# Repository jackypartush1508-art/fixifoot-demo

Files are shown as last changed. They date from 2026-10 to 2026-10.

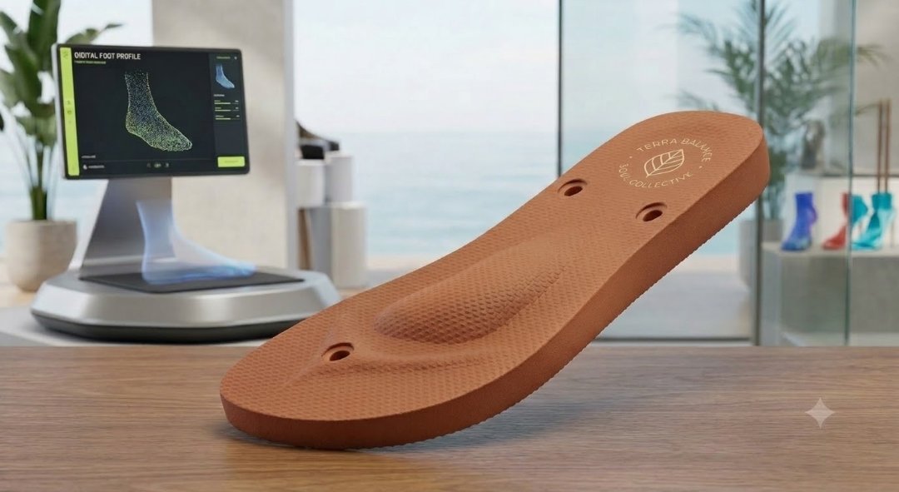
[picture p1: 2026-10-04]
assets/insole-fullcontact.jpg

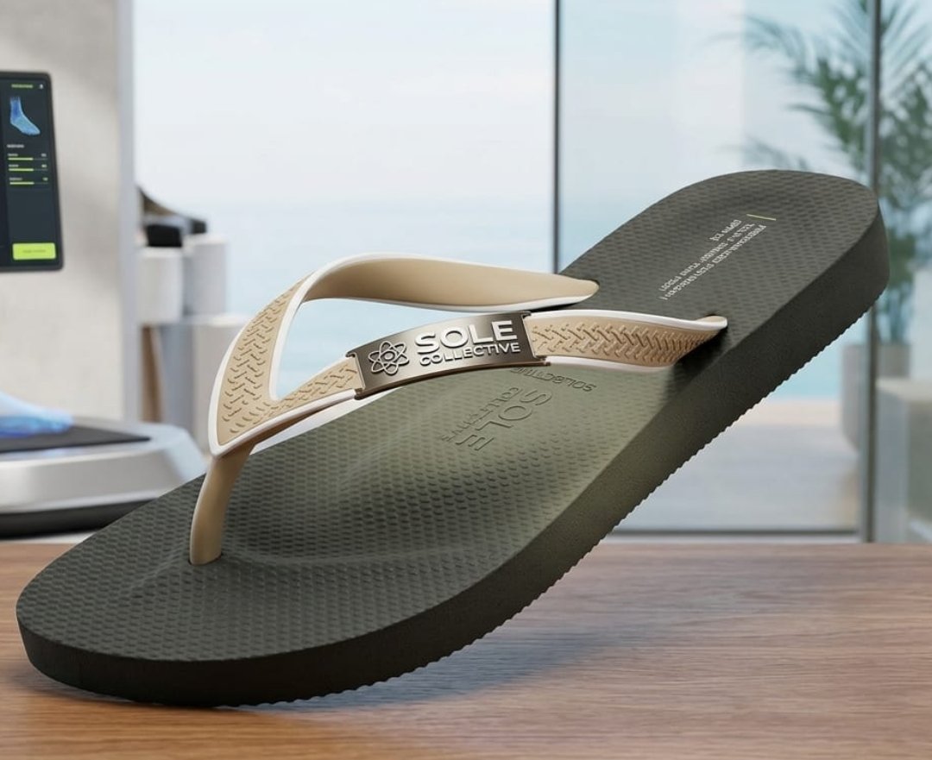
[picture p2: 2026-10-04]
assets/flipflop-classic.jpg

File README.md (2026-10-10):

# Fixifoot Philippines – custom insole & flip-flop DEMO

Static web app (no build step). Serve the folder and open on a phone:

    python3 -m http.server 8000      # then open http://<your-computer-ip>:8000
    # Camera needs HTTPS or localhost. For phones on Wi-Fi use e.g. `npx localtunnel` / ngrok, or upload a scan file.

## Files
- index.html, styles.css – UI (mobile-first)
- app.js       – flow, customer/staff mode, viewers, export
- rules.js     – EDIT ME: arch types, 21 foot problems -> insole changes, questionnaire, friendly wording, products, example prices
- geometry.js  – procedural foot, insole/sole/flip-flop/slide geometry, printable STL builder, template adaptation
- receipt.js   – v10 PDF receipt (jsPDF, vendored in vendor/jspdf.umd.min.js; DejaVu Sans subset in vendor/fonts/receipt-fonts.js)
- footwear.js  – v13 sandal straps, clog upper + heel strap, bed fit / print-time estimate
- engrave.js   – v9 initials engraving as real geometry (manifold-3d booleans, lazy-loaded)
- vendor/      – three.js r160 (vendored, works offline); manifold/ (manifold-3d 3.5.4, Apache-2.0); fonts/fx-font.js (Helvetiker Bold subset)
- assets/      – product photos, templates/ (Jacky's L90 + S90 insoles, repaired watertight STL)

## Modes
- Customer mode (default): simple words, one question per screen, "Your feet -> We'll add" summary.
- Staff mode: tap "🔒 Staff", PIN 1234 (change STAFF_PIN in app.js). Shows checklist, overrides, support settings, conflicts, template choice and "Send to production" (JSON spec + STL per foot).

## Shortcuts for demos
    ?demo=flat&cond=plantar_fasciitis,metatarsalgia&product=fullcontact&screen=s-result&staff=1

## What is simulated
Camera capture is a demo animation; measurements for a demo scan are generated. Real 3D phone scanning needs a native app
(iPhone TrueDepth/LiDAR via ARKit, or an Android photogrammetry SDK). Uploading a real STL/OBJ scan works.
Not a medical device – comfort product; refer diabetes/pain to a podiatrist.

## v3 (Oct 2026)

### Realistic 3D foot, full 360°
- Foot mesh: **"Blender Foot realistic" by Dan Ulrich / Blender Studio** (Human Base Meshes bundle v1.2.0), **CC0 1.0 public domain** –
  https://commons.wikimedia.org/wiki/File:Blender_Foot_realistic_by_Dan_Ulrich_(CC0).stl .
  Decimated 3.0M → 34k triangles, cut at 118 mm (ankle) and capped, mirrored for the right foot, stored in `assets/foot-scan.js` (int16).
  At runtime it is scaled to the scanned length/width, mirrored for L, and the medial arch is deformed per arch type (high +7 mm, low −3.5, flat −6.5 at ~41 % of length).
- Viewer: TrackballControls (no polar limits – rotate over the top and under the sole), pinch/scroll zoom, auto-spin on load,
  preset views Top / Bottom / Inside / Outside / Back / Front, Right / Left / Both, toggles: 🔥 plantar pressure, 🕸 mesh wireframe, ✨ scan look (point cloud shimmer).

### Branding
- Logo: official Fixifoot logo from https://fixifoot.ph/wp-content/uploads/2023/10/fxf_horizontal_logo-21_2.webp → `assets/logo.png` (swap this one file to change it).
- Palette (Elementor global colours on fixifoot.ph): primary `#0099FF`, deep blue `#015AD8`, dark `#162327`, accent yellow `#FFD22E`, light grey `#ECECEC`, black text `#000000` (+ secondary blues `#0A6EBD`, `#5A96E3`, `#A1C2F1`).

### On-device CRM (staff → 📇 Customers)
localStorage key `fxCRM_v1`: name, phone, L/R scan data (incl. 48×24 plantar height grid for uploaded scans), detected problems, settings, order history.
Search by name/phone/order no. **New order from saved scan** regenerates spec + both STLs without rescanning. Two demo customers are seeded on first run.

### Clinical review (staff → 🩺 Clinical rationale)
Arch apex ~41 % of foot length (navicular); arch by type high 20 / normal 15 / low 12 (cap 16) / flat 10 (cap 14) mm;
heel cup 12 standard – 14/16 control – 18-20 deep (KevinRoot, Pacific Orthotic Rx); medial post 4° std, max 6°; lateral wedge ≤5°;
met pad apex 6–11 mm proximal to met heads 2-4 (~66 % length; Hastings 2007); heel lift ≤6 mm in-shoe, >10 mm external (Cochrane 2021, OHI);
zone thickness heel ~3 mm → forefoot ~1.8 mm (sulcus); diabetic: total contact, ≥6.4 mm (1/4") cushioning, no posting, rounded edges (IWGDF 2023, CMS LCD L33369).
**Total contact**: when a real scan (STL/OBJ) is uploaded the insole top follows the scanned plantar surface (rearfoot + midfoot, 85 % of height); toggle in the dashboard.

## v4 (Oct 2026) – scan-accurate fitting (`fit.js`)

### 1. Auto-alignment of uploaded STL/OBJ (staff → 🧭 Scan alignment)
- Units: the scale (m / cm / mm) that makes the scan 150–1000 mm long. Staff can override.
- Clean-up: vertices welded, only the largest connected piece kept (floating debris removed).
- Up direction: sphere search (500 directions + hill-climb) for the direction whose lowest slab has the biggest touching area (the sole).
- Floor (plantar plane): RANSAC + refinement for a supporting plane under the lowest points (≤1 % of points may be below it), then tilt-corrected so the floor is at y = 0.
- Long axis: PCA of the footprint (<25 mm). Heel vs toe: the ankle/leg mass sits over the heel; without an ankle, the forefoot is the wider end.
- Left / right: the medial arch side is higher. If the arch is flat, the longest toe marks the inside.
- Ankle/leg above 40 mm is ignored for the plantar map, and the 3D view clips it.
- Staff view: aligned scan on the floor grid, trim plane, heel→toe arrow, auto-detected values, 2 mm plantar height map.
  Nudges: swap heel/toe, upside down, mirror L↔R, turn 90°, pitch/roll ±1°, yaw ±2°, units, reset.
  The scan is assigned to the detected foot, then the other foot is scanned or uploaded.

### 2. Full-length total contact
- The plantar surface is rasterised as a lower envelope on a **2 mm grid**. It uses only sole triangles flatter than ~65°, so side walls do not lift the rim. One light smoothing pass, and the surface is extended past the outline.
- Insole top = plantar surface × arch fill + one constant. Then:
  - heel cup walls rise from the **scanned heel contour**;
  - clinical modifications are added on top (met pad 6–11 mm behind the measured ball line, posts, wedge, heel lift, toe crest at the measured sulcus, Morton's extension, offload pockets).
- Thickness changes only linearly from heel to toe, so the foot can follow it as a rigid pitch. Bottom is flat on Z = 0.
- Arch fill by condition: default 100 %, arthritis 90 %, plantar fasciitis + high arch 95 %, diabetic always 100 %. Staff slider 70–100 %.
- The plantar height is capped 2 mm above the measured arch apex, so the rim never climbs the side of the foot.
- Outline = scanned footprint silhouette (<20 mm) + product allowance:
  - insole: side 1.5 / heel 1 / toe 6 mm, or trimmed to the shoe last length when an EU size is chosen;
  - flip-flop / slide: side 6 / heel 5 / toe 8 mm.

### 3. Template morphing (L90 / S90)
- XY warp, non-uniform and piecewise-linear along the length: knots at heel / template arch apex → scanned arch apex / template ball → scanned ball line / toe (S90 = 72 % coverage). Width maps onto the scanned outline row by row.
- Z: the top surface follows the plantar map + cup + mods. A single constant keeps ≥ the minimum thickness over the template's own curved bottom (98 % of the bed). The template rim shape is kept.

### 4. Flip-flop / slide
- Contoured footbed from the plantar map, flat outsole on Z = 0, 5 mm heel-to-toe drop (linear).
- Toe-post position = detected 1st/2nd toe gap (4 mm proximal). Strap ends = ball-line landmarks (ballU − 10 %).
- The coordinates are written to the spec (`strapHolesMm`, in the STL frame). Holes are **not** cut into the STL.

### 5. Fit check (staff → 📊 Fit check, badge on the dashboard)
- The product's top surface is rasterised on the same 2 mm grid.
- Foot placement = robust least-squares offset + tilt (the foot standing on the insole).
- gap = scanned sole − insole top. Positive = air gap, negative = pressure.
- Stats over the contact area (plantar height ≤25 mm, edge eroded 4 mm): mean |gap|, signed mean, max gap / pressure, p95, % within ±1 / ±2 mm.
- Intentional modifications are hatched and reported separately.
- **PASS** = mean |gap| < 1 mm and ≥ 80 % within ±1 mm. WARN < 1.6 mm. Otherwise FAIL.
- Views: 3D heat map with ghost foot, plus a 2D deviation map with ball line and toe-gap markers.

### 6. Test scans (`samples/v4-test-scans/`, generator `generate_test_scans.py`)
All test scans are deformations of the CC0 Blender foot (no real customer scan was available).
- flat 255 mm rotated
- high arch 275 mm in cm, rotated
- left foot in metres, Z-up, rotated
- original with leg (left, m, Z-up)
- noise 0.35 mm + debris
- 8° tilt
- low arch OBJ in cm

Results: `fit-results.json` / `fit-results-summary.txt`. All 8 got side, units, heel/toe and length right (±2 mm).
Plantar-map error vs ground truth: 0.02–0.34 mm mean (0.62 mm with noise).
Fit mean |gap|:
- 0.09–0.14 mm (noise scan 0.30–0.41 mm) for contact insole, L90, S90, flip-flop and slide;
- 98–100 % within ±1 mm (noise 93–96 %); p95 ≤ 0.6 mm (noise ≤ 1.5 mm).
All 32 exported STLs are watertight, winding-consistent and have Z = 0 at the bottom.
Limits: see the v4 report (the fit check measures against the same scan the product was built from; real feet deform under load).

## v5 (Oct 2026) – cloud CRM on Supabase (`cloud.js`, `config.js`, `supabase/`)

The CRM can live in Supabase (Postgres + Auth + Storage) instead of the browser. **The cloud switch is `config.js`:**

```js
window.FIXI_CLOUD = { url: 'https://<project-ref>.supabase.co', anonKey: '<anon / publishable key>' };
```

* Empty `config.js` (as published right now): fully offline demo, so the on-device CRM and staff PIN 1234 work exactly like v4.
* Filled `config.js`: the staff button opens **email + password sign in / create staff account / forgot password**. In cloud mode there is no PIN. If the network or the cloud is down, the app falls back to the PIN and the on-device CRM.
* Only the public anon key goes in the frontend; never put the service_role key in it. All access is enforced by row-level security (RLS).

**Database** (`supabase/migrations/20261004120000_fixifoot_crm.sql`)

| Object | What it holds and who can access it |
|---|---|
| `staff_profiles` | user_id, email, name, role pending / staff / admin. Created automatically on sign-up as **pending**. |
| `customers` | id, name, phone, email, notes, profile jsonb (questionnaire, overrides, settings), created_at/updated_at, created_by. |
| `scans` | customer_id, side L/R, source, `mesh_path` (raw scan STL in the `scans` bucket), `plantar_map` jsonb (2 mm height map), `metrics` jsonb, created_at/by. |
| `orders` | order_no, customer_id, product, color, size, problems/settings/spec jsonb, `stl_paths` (in the `stl` bucket), status, created_at/by. |
| Storage buckets `scans` and `stl` | Private, 50 MB per file. |

**Access rules (RLS)**

* anon has no grants at all.
* Pending users see nothing.
* staff can read, insert and update.
* Only admins can delete or change roles.
* Nobody can promote themselves.

**What the app does in cloud mode**

* 💾 Save customer upserts the customer and adds a scan row per changed foot, uploading the raw STL/OBJ scan as STL.
* Send to production and Re-order upload the generated STLs and spec and create an order.
* 📇 Customers loads from the cloud: search, detail, order history and re-order from the saved scan.
* **Customer-facing flow needs no login.** Orders placed without a staff session stay on the device. After signing in, staff see a **⬆️ Upload on-device customers** button.
* Admins get **👥 Staff accounts** to approve sign-ups (pending → staff / admin).

**Setting it up**

1. Apply the migration to the Supabase project.
2. Fill in `config.js`.
3. Add the site URL to Auth → URL configuration, so confirmation and reset emails come back to the app.
4. Jacky signs up in the app (Staff view → Create staff account) and confirms his email.
5. Run `supabase/promote_admin.sql` with his email.
6. Once all staff accounts exist, switch off **Auth → Sign In / Providers → Allow new users to sign up**. New staff are then invited from the dashboard (Auth → Users → Invite), or sign-ups are switched on briefly. Pending accounts have no data access in any case.

### v5 live status (4 Oct 2026)

**Project and keys**

* Supabase project **fixifoot**: ref `kbeplmkinzynpelatzqs`, region ap-southeast-1, free plan, URL https://kbeplmkinzynpelatzqs.supabase.co.
* `config.js` holds the **publishable** key only.

**Migrations applied**

* `fixifoot_crm`
* `private_role_helpers`: moves the SECURITY DEFINER role checks to a non-exposed `private` schema.

**Advisors and tests**

* Security and performance advisors: 0 findings.
* End-to-end test on the live site passed and its data was removed: pending / staff / admin permissions, save, upload, order, search, re-order, delete and sign-out.

**Email**

* With Supabase's built-in email sender, only email addresses of **members of the Supabase organization** are accepted. Others are rejected with `Email address "…" is invalid`.
* For other staff, either set up custom SMTP (Auth → Emails → SMTP settings) or create their user in Auth → Users → Add user, ticking "Auto confirm user".

## v6 (Oct 2026) – real holes and lattice in the STL (`openings.js`)

Ventilation holes (perforated insole) and lattice openings (lattice slide) used to be visual only (alpha textures). They are now **real geometry**: the 3D preview and the exported STL are the **same mesh**.

* **How it works (2D profile, no CSG):**
  * The sole is re-meshed on a tile grid in its own (length × across) parameter space.
  * Each tile that gets an opening is re-triangulated: a zipper between the tile border and the opening polygon, plus a vertical wall from top to bottom.
  * Every edge is shared by exactly two faces, so the mesh stays watertight and manifold.
  * It works on both the scan-based total-contact sole and the parametric sole.
* **Perforated insole:**
  * Through-holes of Ø 3 / 3.5 / 4 mm (12-sided).
  * Spacing Low 9 / Medium 7.5 / High 6.2 mm, staggered rows.
  * Kept solid: heel cup (first 25 % of length), medial arch support (25–62 %), toe end, a 5 mm edge margin and the metatarsal-pad dome when prescribed.
* **Lattice slide:**
  * Through hexagon cells: Low 12 mm / 2.4 mm walls, Medium 9.5 / 2.0, High 7.5 / 1.6.
  * Kept solid: a 7 mm perimeter rim and both strap-anchor bands.
* **Wall thickness:** at least 1.2 mm guaranteed (3 perimeters with a 0.4 mm nozzle). The target is 1.6 mm for holes and the preset wall for lattice. Each opening is checked against its tile border (≥ wall/2) and the outline (≥ rim), and is shrunk or skipped if it doesn't fit.
* **Staff controls:** Product & model → *Real ventilation holes / Real lattice openings* on/off, density/spacing, hole diameter. Live stats show the count, open area, min wall, rim and triangles. The setting is saved with the customer and written to the spec JSON (`product.openings`, `stlFiles[].openings`).
* **Template base (L90 / S90):** holes are **not** cut into template models. Use the parametric or scan sole for real openings.
* **Samples:** `samples/v6-perforated-insole-holes-{right,left}.stl`, `samples/v6-lattice-slide-sole-{right,left}.stl`.
* **Screenshots:** `screenshots/v6-*.png`
  * `v6-stl-*`: the exported STL rendered directly.
  * `v6-staff-*` and `v6-preview-*`: the in-app viewer.

## v6.1 (Oct 2026) – smooth forefoot, no ridges between the toes (`fit.js`)
- Scan-based surface (`deriveModel` → `md.sampleF`): from ~14 mm behind the metatarsal-head line forward the scanned relief is replaced by a
  robust, lower-envelope-weighted **quadratic surface** (1, t, t², s, s², s·t in a fixed ball-row frame) – a template-like forefoot with gentle toe
  spring. It is blended into the scanned arch/heel with a smoothstep over ~18 mm (ballU − 14 mm → ballU + 4 mm): no step, no kink.
- Used by every scan-based model (full-contact, perforated, slide, flip-flop, morphed templates). Prescribed modifications (met pad, toe crest,
  Morton's extension, reliefs) are still added on top. The parametric path was already analytic/smooth in the forefoot (verified).
- The fit check ignores the intentionally smoothed forefoot zone ("Smooth forefoot (no toe ridges)").
- Validation (trimesh, 1 mm ray grid, toe zone 4 mm → 24% of length from the tip, ≥ 6 mm inside the outline, residual to a cubic polynomial):
  before v6.1 max 6.9–8.8 mm (toe ridges), after **0.10–0.14 mm** (p99 0.07–0.08 mm); parametric 0.11–0.19 mm. All 20 STLs watertight, 1 body,
  min wall ≥ 1.68 mm. Curvature across the blend zone: max |d²z| 0.05 mm/mm² (was 1.16).
- Screenshots: `screenshots/v6.1-before-toes-*.png`, `v6.1-after-toes-*.png`, `v6.1-*-iso-*.png`, `v6.1-staff-*.png`. Samples: `samples/v6.1-*-{right,left}.stl`.

## v7 (Oct 2026) – Fixifoot insole line: 6 new models (`rules.js` PRODUCTS, `fit.js`, `geometry.js`, `app.js`)
Every model is built on the v6.1 smooth-toe surface (scan path) or the analytic parametric surface. Each product has `model` (real geometry),
`params` (forced clinical settings) and `print` (TPU print settings) – stored in the spec JSON (`print`, `model`, `recommended`) and shown in
staff mode (Product & model card → model geometry + TPU print settings table).

| Model | Geometry (STL) | Print |
|---|---|---|
| **Fixifoot Sport** | 8 → 6 mm (heel → forefoot), 18 mm heel cup, arch +1.5 mm | TPU 95A gyroid 20%, heel shock zone gyroid 35%, 85A soft top 1.2 mm |
| **Fixifoot Everyday** | 4 → 3 mm, 10 mm gentle heel cup, full-contact arch, real ventilation holes | TPU 90A gyroid 25%, 0.16 mm layers |
| **Fixifoot Diabetic Care** | 7 → 6.2 mm (min 6), total contact, 1.4 mm rounded rim, 1.5 mm smooth soft-insert pockets under met heads + hallux | varioShore / TPU 80–85A gyroid 15%, pockets 8% or PORON, 3 mm soft top cover |
| **Fixifoot Work & Stand** | 5.5 → 5 mm, strong arch +3 mm, 16 mm heel cup | TPU 92A, heel + ball cushion zones gyroid 12%, arch 35% |
| **Fixifoot Dress Slim** | 3/4 length (ends 6 mm past met-head line), 3 → 2.2 mm with skived front, met pad, 10 mm cup | TPU 95A solid, 0.12 mm layers |
| **Fixifoot Kids** | 3.2 → 2.2 mm flexible forefoot, arch fill 75%, 14 mm cup; thickness + cup scale with foot length (ref 240 mm) | TPU 85A gyroid 15%, forefoot 10% |

- Rule engine `recommendProduct()`: diabetes → Diabetic Care; foot < 215 mm → Kids; sporty → Sport; 8+ h standing → Work; otherwise Everyday.
  The customer picker shows the recommended model first with a "⭐ Recommended for you" badge; staff mode shows it with a "use it" link.
  A diabetic customer on a non-diabetic model gets a production conflict warning.
- Prescribed met pad is kept on every model; template bases (L90/S90) are disabled for the v7 models (they have their own geometry).
- Samples (right foot): `samples/v7-<model>-right.stl` (kids sample from a 191 mm kid-size scan). Renders: `screenshots/v7-render-<model>.png`.
  Staff screenshots: `screenshots/v7-staff-<model>.png`. Catalog images (model cards): `catalog/<model>.png`; catalog sheet: `catalog/fixifoot-insole-line.png`
  (rendered from the real STLs with Fixifoot colours #0099FF / #015AD8 / #FFD22E).

## v7.1 (Oct 2026) – marketing illustrations for the insole line
- Customer model picker uses marketing illustrations `catalog/<model>-hero.jpg` (960×540, 27–48 KB) with the caption
  "Illustration – your insole is custom-made from your scan". The real STL render (`catalog/<model>.png`) is shown in staff mode as
  "Actual print preview". New catalog sheet: `catalog/fixifoot-insole-line-v2.png`. Service worker cache `fixifoot-demo-v7-1-1`.

## v8 (Oct 2026) – 2-material print files for dual-extrusion printers (`multi.js`)
Each of the 6 line models is split into **two scan-fitted bodies** that fit together exactly. Both bodies are cut from one shared 2D plan of the sole, so the
interface surface uses the same vertices in both files: no gap, no overlap. Each body is a closed, consistently oriented mesh.

| Model | Extruder 1 | Extruder 2 | How it is split |
|---|---|---|---|
| Sport | Black TPU 95A base | Blue TPU 85A top layer 1.8 mm + heel cup | Layers. The base has a hexagonal lattice (1.6 mm ribs) in the heel and open windows in the heel side walls. |
| Everyday | White TPU 90A base | Light-blue TPU 85A top 1.5 mm | Layers. Ventilation holes go through both bodies. |
| Diabetic | White soft TPU / varioShore base | Extra-soft inserts (ball, big toe, medial arch band) | Inserts. They fill the pockets full depth and sit flush with the top. |
| Work | Grey TPU 95A/92A shell | Yellow TPU 85A hex cushions | Inserts. Hexagonal windows (2 mm ribs) in the heel and forefoot are filled by the cushions. |
| Dress | Nude TPU 95A 3/4 body | Light-nude TPU 85A raised met pad | Inserts. |
| Kids | Orange TPU 90A base | Blue TPU 85A top 1.5 mm | Layers. |

- **Layer split.** The top layer thickness is measured perpendicular to the surface (slope-compensated), so the heel-cup walls keep their thickness. The base is never thinner than 1.2 mm where the sole is at least 2.4 mm thick.
- **Staff → "2-material print" card.**
  - Download 2-material 3MF (Right/Left).
  - STL per body (Right/Left).
  - A 2-colour view toggle.
  - A body/extruder table with minimum thicknesses.
  - The render from the actual file.
  - The single-STL buttons are unchanged.
- **3MF contents.**
  - Core spec: basematerials with names and display colours, one mesh object per body, and an assembly object as the build item.
  - `Metadata/model_settings.config`: Orca/Bambu parts with extruder 1/2.
  - `Metadata/Slic3r_PE_model.config`: PrusaSlicer volumes with extruder.
  - `Metadata/fixifoot_print_settings.json`, plus a `fixifoot:printSettings` metadata entry.
- **Samples and images.**
  - Samples: `samples/v8-<model>-right.3mf`.
  - Renders from the real 3MF: `catalog/<model>-actual.png`.
  - Comparison sheet: `catalog/hero-vs-actual.png`.
  - Service worker cache: `fixifoot-demo-v8`.

## v8.1 (Oct 2026) – sandal illustrations + thin-toe fix
- **Picker cards:** the flip-flop and slide cards now use marketing illustrations: `catalog/flipflop-hero.jpg` (Arch Flip-Flop) and `catalog/slide-hero.jpg` (Lattice Slide). Each card has the caption "Illustration – your product is custom-made from your scan".
- **Custom Scan Flip-Flop image:** there is no separate contoured/scan flip-flop card, so `catalog/flipflop-scan-hero.jpg` is a small detail thumbnail on the flip-flop card. Tapping it swaps the two images. The old photos are kept as `photo`.
- **Collection sheet:** `catalog/fixifoot-collection-catalog.png` added.
- **Thin-toe fix:** the Everyday and Kids generic-size (no scan) builds now keep at least 2.4 mm total thickness (`model.minTotal`), raised only at the toe tip and edge. Each of the two layers therefore stays at least 1.2 mm.
- **Cache:** service worker cache `fixifoot-demo-v8-1`.

## v8.2 (Oct 2026) – correct left/right foot view + clean insole outline
- **3D foot preview (Both view).**
  - **What was wrong:** the Right foot was placed on −x and the default camera looked from the toes (facing the person). The result was a mirror image: the foot labelled Left was on the left with its big toe pointing outward.
  - **Fix:** the right foot is now on +x, and the default 3D view looks from behind/above, the way the person sees their own feet. Left is on the left, Right on the right, big toes on the inside. Top and Back presets match this; Front and Bottom are true facing/underneath views.
  - **Unchanged:** the single-foot views, the Inside/Outside presets and the 2D pressure map were already correct.
- **Left/right in the insole files.** The geometry and exports (STL, 3MF, per-body STL) were already correct for every case tested: demo feet, an uploaded right scan and an uploaded left scan. The medial arch is on the inside and right = right.
- **Insole outline (`geometry.insoleShape`).** A new classic insole-last shape: narrow rounded heel, gentle arch waist (deeper on the medial side), widest at the metatarsal heads, rounded toe with the apex slightly medial.
  - The generic/parametric insoles, flip-flop and slide soles all use it.
  - Scan-based soles now use the same shape (`fit.insoleFrame`), laid on the scanned heel→ball axis and scaled to the scanned ball width, heel width and length. The raw silhouette was used before.
  - The 3/4 models get rounded front corners.
  - Screenshots: `screenshots/v8.2-outline-before.png`, `-after.png`, `-left-right.png`.
- **Service worker cache:** `fixifoot-demo-v8-2`.

## v9 (Oct 2026) – design first, then scan
Customers now pick and design their product **before** the scan ("sell the design first").

**Customer flow:** Welcome → **Design my pair** → Catalog (all 9 products with photo, tagline, default colours and price) → Designer → Summary card (design + price) → **Scan my feet** (right, then left) → questions → results → order.
- **Catalog** (`rules.js` `CATALOG`): Everyday, Sport, Work & Stand, Diabetic Care, Dress, Kids, Arch Flip-Flop, Custom Scan Flip-Flop, Lattice Slide.
- **Designer:** live 3D preview of the real product geometry (generic EU 41, or the chosen size), colours update instantly. Pick a colour for extruder 1 (base / sole) and extruder 2 (top layer / inserts / strap) from 12 TPU filament colours (`PALETTE`): Black, White, Grey, Fixifoot Blue #0099FF, Light blue, Orange, Yellow, Olive, Beige/Nude, Red, Pink, Purple. Optional initials (max 6: A–Z, 0–9, & . - '). Optional size (otherwise the scan measures it).
- **Price:** ₱9,999 for every product by default. To change it, staff open **💲 Prices** (saved on the device in `localStorage.fxPrices_v1`), or set `window.FIXI_PRICES = { default: 9999, sport: 8999, … }` in `config.js`. Priority: device setting > config.js > 9,999.
- **After the scan** the chosen design is fitted to the scan. If the rule engine prefers another model (e.g. diabetes → Diabetic Care), a gentle tip offers "Switch (keep my colours)" or "Keep". The customer's choice stays unless they or staff change it (`design.changedBy`, `design.keptSuggestion`).
- **Staff:** the scan-first path is still there ("Staff: scan first (classic flow)" on the welcome screen in staff mode). The staff panel shows a **🎨 Customer design** card (edit the design) and the price editor.

**Engraving (real geometry, `engrave.js`):** letters are 8 mm high (down to 6.5 mm if needed), 0.6 mm deep. Every stroke and gap is at least 1.2 mm (morphological close + open, r = 0.6 mm). They are placed on the heel (Work: midfoot between the cushions; Diabetic: on the underside, so the top stays smooth) and read correctly from above with the toes pointing up.
- Two-material insoles: the top layer is cut through in the letter shapes and the base colour fills them up to 0.6 mm below the surface, giving a two-colour inlay.
- Single STLs: a 0.6 mm pocket.
- No lattice cells or holes are placed under the letters, so the letter floor stays solid.
- The slide lattice gets a solid label patch.
- Every engraved body is checked closed in float32 (`closedF32`) and repaired by micro-simplify if needed (`ensureClosed`).

**Saved with the order:** `spec.design` (product, colours per extruder with hex/name/material, initials plus engraving info, size, price) and `spec.price`. The 3MF material names, displaycolor and `fixifoot_print_settings.json` use the chosen colours. Cloud: migration `supabase/migrations/20261004160000_orders_design.sql` adds nullable `design jsonb, price_php, engraving_text (≤6), color_ext1, color_ext2` to `orders`. It is additive only and RLS is unchanged (staff-only policies; anon is denied).

**Validation** (`samples/v9-validation.json`, test design Sport black/orange "JP"): 32 STLs, all watertight, consistent winding, volumes. Min vertical wall 1.5 mm, no parts narrower than 1.2 mm, min rib 1.77 mm. Two-body interface overlap ≤ 0.02 mm³. Left/right correct. 3MF: 2 objects / 1 build item, no lib3mf warnings. Screenshots: `screenshots/v9-*.png` (iPhone 13 size).
- Note: the Arch and Custom Scan flip-flops share the scan-fitted sole geometry.
- Note: flip-flop and slide colours are recorded in the spec; they print as a single sole STL.

## v10 (Oct 2026) – production mode + PDF receipt
**No demo mode for customers.** The DEMO badge, “(demo)” texts, simulated camera scan and default demo feet are gone. Old sample customers (C-DEMO*) are removed from the device.
- **Scan step:** customers upload a real 3D scan, right foot first, then left. STL, OBJ and PLY are accepted (e.g. exported from KIRI Engine), and a short “how to scan with your phone” guide is shown.
- **Staff fallback:** 📏 Manual measurements. Staff enter length, width at the ball and arch type per foot. The 3D foot is then labelled “illustration from measurements” (the CC0 foot mesh is used only as an illustration, never as “your scan”). Orders and the spec say “manual measurements”.
- **Staff test tool:** Settings → “Test tools” turns on 🧪 “Test with sample feet”. It is hidden for customers. Sample feet are marked as test data everywhere (spec `testData: true`, receipt “TEST – NOT A REAL ORDER”). The URL hooks `?demo=` and `?staff=1` only work on offline devices or with test tools on.
- **Staff access:** cloud sign-in. The shop PIN (`window.FIXI_STAFF_PIN`, default 1234, no longer shown on screen) is only offered when the cloud is unreachable (health check) or not configured, together with a note to staff that data stays on the device until it is uploaded.

**PDF receipt** (`receipt.js`, generated in the browser, works offline and in the standalone file):
- Created when an order is completed (thank-you screen) and from Customers → customer → 🧾 Receipt on every order.
- Content: logo, Fixifoot Philippines, fixifoot.ph, receipt/order no. (FXF-…), date/time in Asia/Manila, customer name, mobile and email. Items: product, colours per part, initials, size, foot length L/R, unit price, qty 1 pair. Then subtotal, discount, total in ₱, payment method (Cash, GCash, Maya, Card, Bank transfer), paid/unpaid, staff name, notes, thank-you + TPU care instructions, and the footer “Comfort product, not a medical device”.
- Buttons: Download PDF · Share (Web Share API with the PDF file; falls back to download) · Print.
- **Business details** (Staff → Settings, or `window.FIXI_BUSINESS = { name, address, tin, phone, email }` in config.js) are blank by default; no TIN is invented. Without name, address and TIN the PDF is titled **Acknowledgement Receipt** and says it is not an official BIR receipt.
- **Cloud:** migration `20261004180000_orders_payment.sql` adds optional `payment_method` (checked list), `paid`, `discount` (≥0) and `receipt_no` (unique when set) to `orders`, and allows the scan sources `manual` and `sample`. RLS is unchanged.
- Sample: `samples/v10-receipt-sample.pdf` (TEST customer); page 1 is shown in `screenshots/v10-receipt.png`. Scan step screenshots: `screenshots/v10-*.png`.

## v11 (Oct 2026) – CRM upgrade (staff mode)
Staff dashboard → **Customers & orders** now has five tabs. The layout is built for phones: tabs and the board scroll sideways and buttons are large enough to tap.
- **Customers**: search by name, phone, email or order no. The **Filters** panel adds tag, product, status and a from/to date range; the same filters apply to every tab and to the exports. Tap a customer to open the **customer card**:
  - editable name, mobile and email; tags (**Diabetic**, **Athlete**, **VIP** plus custom tags); internal staff notes
  - every order with a status selector and dated status trail, plus 🧾 receipt (PDF download, share or print)
  - scan history by date with **View 3D**. The original scan is loaded from cloud storage when it exists; otherwise the viewer shows a labelled illustration built from the measurements.
- **One-tap reorder** from the saved scan: **↻ Same again**, or **🎨 Change product / colours** to pick a product, a colour for each part, and initials. Both regenerate the print files and spec with no new scan and record the order as `reorder`.
- **Orders**: a **Board** (kanban: New → Printing → Ready for pickup → Delivered, plus Cancelled, with ◀ / ▶ / ✕ move buttons) and a **List** with a status selector. Every change is stamped `{status, at, by}`.
- **Reminders**: orders *Ready for pickup* for more than 3 days (Call / SMS / Delivered ✓), and customers whose last order was 6–12 months ago (replacement due, with a Reorder button).
- **Reports**: revenue, order count, average order, and unpaid total; sales by day and by month; top products; revenue by payment method. Reports count real orders only, excluding cancelled orders and any test or sample-scan order (customer name containing "TEST", or sample feet). Revenue is price − discount, and dates are in Philippine time.
- **Export**: customers CSV, orders CSV (UTF-8, opens in Excel or Sheets) and an `.xlsx` workbook with *Customers* and *Orders* sheets. All exports follow the current filters. Sample: `samples/v11-crm-export-sample.xlsx`.

Database: migration `supabase/migrations/20261004190000_crm_status_tags.sql` adds:
- `customers.tags text[]` (the existing `notes` column holds staff notes)
- `orders.status_history jsonb` and `orders.status_updated_at`
- trigger `orders_status_stamp`, which records each status change on the server with `auth.uid()`
- indexes on status, created_at and tags

RLS is unchanged: staff read/insert/update, admins delete, and anonymous users have no access. Screenshots `screenshots/v11-*.png` were taken with local sample data (Customer 01–08 plus one TEST customer to show it is left out of reports); no sample data was written to the cloud.

## v11.1 (Oct 2026) – Continue without scan
- **Customers** (no staff login needed) can tap **Continue without scan →** on the scan-upload screen. They then enter:
  - shoe size in **EU / US Men / US Women / UK**, or foot length in **cm**. The size applies to both feet by default; tick "left foot is a different size" to enter each foot.
  - optional width: narrow / normal / wide
  - arch type (flat / normal / high), picked from simple footprint pictures
- The flow then continues as usual: preview, analysis, questions, results and order. The 3D foot is labelled *"illustration from your measurements – scan pending"*, and the order screen and thank-you card explain that a scan will be taken before printing.
- **Scan pending** marking:
  - set on the order and the customer (feet source `self`; staff manual measurements count too)
  - shown as a badge in the CRM list, on the board and in the order list
  - **Scan** filter: pending / has 3D scan
  - **📷 Needs scan** list in Reminders
  - a column in the CSV / Excel exports
- **Add scan** button on the customer card (also in Reminders):
  - staff upload the STL/OBJ/PLY files (side detected automatically)
  - the pending order's print files and spec are rebuilt from the scan, keeping the same order number and design
  - the flag is cleared; when signed in to the cloud, the scan and the regenerated STLs are uploaded
- **Staff print files from measurements** can still be downloaded. The dashboard shows "⚠ Approximate fit – scan recommended", file names end in `-APPROX`, and the spec carries `scanPending` and `fitWarning`.
- **Database:** migration `supabase/migrations/20261004200000_scan_pending.sql` adds:
  - `customers.scan_pending` and `orders.scan_pending` (boolean, default false), with partial indexes
  - scan source `self`

  RLS is unchanged.
- Screenshots: `screenshots/v11.1-*.png`.

## v11.2 (Oct 2026) – scan-centred CRM (no sales screens)
The staff CRM is now about **customers and their scans**, not sales.
- **Removed:** the Reports tab (revenue, sales counts, charts), money on the order board and list, order prices and receipts in the customer card, and revenue columns in exports.
- **Customer card → Scan visits** (newest first). Each visit shows:
  - **date & time** (Philippine time), stamped automatically when a scan is uploaded or taken
  - foot (**Right / Left / Both**)
  - the **scan file(s)**
  - a **payment** row (amount ₱, **Paid / Unpaid**, method **Cash / GCash / Card / Bank transfer**) that staff can edit in place and that saves immediately

  Each visit also has View 3D (per foot), ✏ Edit (date/time, payment, notes; admins can delete) and 🧾 a receipt for that visit.
- **＋ New scan visit** on an existing customer: upload one or both feet (optional) with date/time, payment and notes. The customer's feet are updated, and any scan-pending order is rebuilt from the new scan.
- **Staff order screen:** "Scan payment" (amount / paid / method) is saved on that day's auto-stamped scan visit.
- **Orders** remain as a secondary tab (status pipeline only, no money). Reminders and Needs scan are unchanged.
- **Export:** customers CSV, **scan visits CSV** (date, time, feet, files, payment amount / status / method, notes), and Excel with *Customers* + *Scans* sheets. Sample: `samples/v11.2-crm-scans-export-sample.xlsx`.
- **Database:** migration `20261004210000_scan_visits.sql` adds table `scan_visits`:
  - `scanned_at`, `feet`, `details` jsonb (files, sources, lengths, scan ids)
  - `payment_amount`, `payment_status`, `payment_method`, `notes`
  - RLS: staff read/insert/update, admins delete, anonymous users have no access

  When not signed in, visits are kept in local storage. Scans saved before v11.2 appear as visits grouped by time; their payment can be filled in, which saves them as real visits.

## v12 – Orthotist engine (fitting the insole to the scan)
- New step between scan analysis and export (`orthotic.js`). It measures each foot: arch height / arch height index, arch type, rearfoot valgus/varus from the 3D heel, ball and heel width, met-head line, toe length, L/R difference, and contact (pressure) zones. It then applies prescription rules: arch support scaled to the measured arch, heel-cup depth, medial or lateral rearfoot posting in degrees, a metatarsal pad behind the met heads, forefoot/hallux relief, a capped heel lift for leg-length difference, diabetic offloading and children's limits.
- The rules and their sources are in **ORTHOTIC_RULES.md**. **They must be reviewed by a licensed orthotist / podiatrist.**
- Corrections apply per foot to the insole and flip-flop/slide geometry. The 2-material 3MF is unchanged.
- Staff dashboard → **🩺 Fitting report**. It shows the measurements and each correction with its value and a plain-English reason. Every value can be overridden before export (overrides are saved with the customer), with a reset button. The **Fitting report PDF** includes a reviewer signature line. The spec JSON carries the fitting report.
- Orders without a scan use conservative defaults and are marked **APPROX**.
- Screenshots: `screenshots/v12-*.png`.

## v12.1 – UI clean-up
- Customer questionnaire cut down to 4 compact questions with no emojis: where it hurts (6 chips), diabetes yes/no, daily activity (Low / Moderate / High, combining hours on feet and sport), and weight (3 ranges). The toes, shoe-wear and "anything else" questions were dropped because the scan and the orthotist engine infer them. Answers saved with older customers are still read. Staff-only extras on the same page: a leg-length difference toggle and notes.
- Scan upload screen: the "How to scan with your phone" card was removed (staff scan in the shop).
- PDF receipt: the header no longer has a Status field, and the care-tips / thank-you box was removed.
- Staff results: the yellow "Approximate fit – scan recommended" box above the STL downloads was removed. Files built without a scan still get the `-APPROX` filename suffix.
- Screenshots: `screenshots/questions-short.png`, `screenshots/scan-upload-no-instructions.png`, `screenshots/receipt-v12.1.png`.

## v13 – Contour Two-Strap sandal + Comfort Clog (`footwear.js`)
Two new scan-fitted footwear products (catalog now 11 products, price ₱9,999 = `DEFAULT_PRICE`, override per product in `config.js` `window.FIXI_PRICES` or staff settings):
- **Fixifoot Contour Two-Strap** (`twostrap`) – contoured footbed with raised toe bar and deep heel cup (≥16 mm), two wide straps (26 mm, scaled with foot length) over the forefoot (≈ ball line) and the instep (52 % of foot length), with a buckle-look tab and 3 holes on the outer side.
- **Fixifoot Comfort Clog** (`clog`) – roomy closed toe box (≈ 6–8 mm toe allowance, 7 mm over the toes, 3 mm at the sides, 2.8 mm wall), honeycomb vents as real through-holes (≈ 33 cells, 15 mm cell / 4.5 mm wall), optional heel strap that pivots on two printed pins (switch in the designer and in staff view).

Geometry
- Sole = the orthotist engine (`orthotic.js` corrections, `fit.js` contact sole) with footwear minimums; 2 bodies: base TPU 95A (extruder 1) + 2.5 mm top TPU 85A (extruder 2) → one 2-material 3MF per foot.
- Straps / clog upper / heel strap are sized from the scan's top-of-foot envelope (`measureUpper`: forefoot + instep height and width along the foot). Without a scan a synthetic foot of the entered size is used and every file is marked **APPROX**.
- Every body is closed (watertight) and exported as its own STL (`Download STL per body`), already laid out for printing: straps on edge, clog upper upright (rim down, organic supports under the roof), heel strap on edge.

Printer bed (staff → 2-material card → “Printer bed”: K1C 220×220×250 / 256 / 300, saved in localStorage `fxBed`)
- The sole is rotated on the bed to its best angle (≈ 40–43° diagonal). On a K1C it fits with a 5 mm margin up to ≈ 250 mm foot length (≈ EU 40), up to ≈ 255 mm with only 2 mm to the edge (shown as ⚠️ tight). Bigger feet need a 256 or 300 bed.
- The clog upper (≤ ≈ 143×141×106 mm even at 300 mm foot) and the straps always fit – no splitting needed.
- Rough print times per foot (250 mm): sole base ≈ 13.6 h, top layer ≈ 11 h, each strap ≈ 3.6–4 h, clog upper ≈ 8.8 h, heel strap ≈ 4.2 h.

Notes: a layered 2-material TPU sole needs a dual-extruder / tool-changer printer (most AMS/CFS units cannot feed 85A). Straps and the clog upper are bonded to the sole edge (TPU-compatible adhesive); the sandal sole has shallow recesses where the strap tabs sit. Designs are Fixifoot's own; no third-party names or logos.
Combined catalog: `/workspace/fixifoot-catalog/src/build-catalog.mjs` rebuilds the 11-product PNG/PDF.

## v13.2 – classic look for the two footwear models
New hero photos (no logos / brand marks). Geometry updated to match:
- **Contour Two-Strap**: chunky one-piece-look sole with a raised rim (5 mm, outside the scanned footprint only), pronounced 6 mm toe grip ridge, 18+ mm heel cup, light tread (1.2 mm chevron grooves in the bottom face, bridged by the first layers). Each strap now carries a molded rectangular buckle (frame + centre bar) and a strap-tail relief – same part, printed on edge, no supports. Sole side allowance 6 mm (rim width).
- **Comfort Clog**: ~13 round Ø11 mm top vents in staggered rows + 2 elongated side vents (15×5.5 mm) per side just above the sole line, all real through-holes; smoother rounded toe box (40 mm nose rounding, ripple-free roof); light tread; swing heel strap on round rivets (Ø16 raised disc + pin), shown swung down round the heel (the strap itself is flat and printed on edge).
- Bed limits unchanged: K1C fits ≤ 250 mm foot with 5 mm margin, ≤ 255 mm with 2 mm.

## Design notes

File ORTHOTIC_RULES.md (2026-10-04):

# Fixifoot orthotist engine – prescription rules (v12)

> **Clinical review required.** These rules turn a 3D foot scan, or entered measurements, into a *starting* prescription. They come from published rules of thumb and common orthotic-lab practice. They are **not** a diagnosis, and the device is a comfort product, not a medical device. A **licensed orthotist / podiatrist must review and approve these rules, and each fitting report**, before anyone relies on them. Review matters most for diabetes, children, rigid deformities, neuropathy or ongoing pain. Staff can override every value in the Fitting report before export.

Code: `orthotic.js` (`measureFoot` → `prescribe` → `applyCorrections`). Glue code is in `app.js` (`fittingFor`, `currentSpec`, `renderFitReport`). The PDF is built in `receipt.js` (`buildFittingPdf`). The engine runs for every product (insoles and flip-flop/slide footbeds), separately for the left and right foot. Its output becomes the geometry parameters that the STL, the 2-material 3MF and the preview are built from.

## 1. Measurements (from the 2 mm plantar height map + the aligned mesh)

| Measurement | How | Notes |
|---|---|---|
| Foot length, ball width, heel width | Map outline (heel → longest toe, widest forefoot row, heel row) | Same values as the fit check |
| Arch height (plantar apex) | Highest point of the medial-arch soft tissue above the floor, 2 mm map | Proxy for navicular height; a scan of the sole cannot see the bone |
| Arch height index (AHI %) | Arch height ÷ foot length × 100 | Fixifoot scan thresholds: **< 6.5 % flat · 6.5–7.8 % low · 7.8–10.5 % normal · > 10.5 % high**. If the Chippaux-Smirak index (CSI) is > 60 %, the type moves one step flatter. Typical arch height = 8.5 % of length. *Calibrated on the sample scans – validate on real patients.* |
| Chippaux-Smirak index (CSI) | Narrowest midfoot contact ÷ widest forefoot contact | Chippaux 1985; Forriol & Pascual 1990. Shown alongside AHI. Footprint indices are known to misclassify some feet, so arch height is preferred. |
| Rearfoot alignment (°) | Posterior heel (back 8 % of length): centre of the heel at 3–12 mm height vs 25–40 mm height. + = valgus/everted, − = varus | Approximates the bisection of the calcaneus seen from behind (resting calcaneal stance position, RCSP). Normal resting stance: about 0–4° everted (Root et al. 1977; Sobel et al. 1999). If the scan has less than about 32 mm of heel height, the angle is **estimated from the arch type** (flat 6°, low 4°, normal 2°, high −2°) and marked "estimated". |
| Met-head line, toe length | Ball line (widest forefoot row) from the heel; ball → toe tip | |
| Pressure zones | Share of "contact" cells (sole within 2.5 mm of the floor) under heel / midfoot / met heads / hallux | A static contact proxy, not a pressure plate. Typical scans show about 45–49 % under the met heads. |
| L/R difference | Foot length difference when both feet are scanned | A foot-length difference is *not* a leg-length difference; each insole is sized to its own foot. |

Feet entered without a scan (measurements or self-measure) are flagged **APPROX**. For these feet the shape comes from a typical foot of that length, width and arch type, and every limit below is the conservative one.

## 2. Corrections

| Correction | Rule | Limits | Source / rationale |
|---|---|---|---|
| **Arch support (extra height)** | Flat or low arch: ½ × (typical − measured arch height); at least 2 mm for flat feet and 1 mm for low arches. High or normal arch: 0 (total contact only). | Max **5 mm** adult; **2 mm** for diabetes, children or APPROX feet. The product model's own arch boost is subtracted. | Partial correction of a *flexible* flat foot is standard. Full correction is poorly tolerated (Kirby 2000; Landorf & Keenan 2000). Assumes a flexible flat foot: a rigid flat foot needs ≤ 1.5 mm, which staff must check by hand. |
| **Arch contact fill** | 100 % (total contact). Diabetes: 95 %. | 60–100 % | Total-contact inserts spread plantar load (IWGDF 2023) |
| **Heel cup depth** | 5 % of foot length; **6.5 %** if the foot is flat or the heel valgus is > 4° | 8–18 mm insole; **max 10 mm** flip-flop; **max 12 mm** child | Deeper cups contain the heel fat pad and help control rearfoot eversion (Kirby 2000; common orthotic-lab practice of 12–18 mm for control devices) |
| **Medial rearfoot post** | Heel valgus > 4°: (valgus − 2°). Flat foot without valgus: 2°. A staff or questionnaire problem of over-pronation / PTTD raises it to ≥ 3°. | **2–6°** adult (Kirby rearfoot posting range). Max 3° for a child, an APPROX foot or an estimated angle; 4° for flip-flops; **2° for diabetes**. | Rearfoot varus posting of 2–6° is typical (Kirby 2000, "Foot and lower extremity biomechanics"; Root functional orthoses) |
| **Lateral wedge** | Heel varus < −2°, or a high arch with negative alignment: (−angle + 1°). A staff or questionnaire problem of supination / ankle instability / cavus gives 3°. Cannot be combined with a medial post. | 2–5° (max 2° for diabetes) | Lateral posting for cavus / supinated feet and ankle instability (Burns et al. 2006, cavus foot orthoses) |
| **Metatarsal pad** | Met-head contact share > 55 % (> 50 % for a high arch), or metatarsalgia, Morton's neuroma, calluses or sesamoiditis. The dome apex sits about 15 mm **proximal** to the met-head line. | Not for diabetes (soft relief instead) or for children without symptoms | A pad proximal to the met heads lowers peak met-head pressure (Hsi et al. 2005; Hayda et al. 1994; Kang et al. 2006) |
| **Forefoot / hallux relief** | Diabetes: soft relief pockets (heel, met heads, hallux). Otherwise: 1 mm 1st-MTP relief for hallux contact > 12 %, hallux rigidus or bunion. | – | IWGDF 2023 footwear and offloading guideline; first-ray cut-outs for hallux limitus (Welsh et al. 2010) |
| **Heel lift (leg-length difference)** | From the questionnaire and staff entry, shorter side only. < 4 mm: none. Otherwise the full difference up to the cap. | Max **6 mm** inside a shoe insole; 8 mm for a flip-flop footbed. Any remainder goes into the shoe or sole. | Gurney 2002 (LLD review); common practice is to correct about 50–100 % and to keep in-shoe lifts ≤ 6 mm |
| **Soft top / no hard edges** | Diabetes | – | IWGDF 2023: accommodative, cushioned, no high-pressure edges |

### Special groups
- **Diabetes** (questionnaire "diabetes: yes" or the Diabetic problem): accommodative, not corrective. Arch lift ≤ 2 mm, posting ≤ 2°, 95 % arch fill, no firm met pad, soft relief pockets, soft top, no hard edges. Refer to a podiatrist; check feet daily. (Bus et al., IWGDF guidelines 2023.)
- **Children** (Kids model or foot < 215 mm): flexible flat feet are normal in many children and often need no orthosis (Evans 2008; Evans & Rome 2011). Limits are arch ≤ 2 mm extra, posting ≤ 3°, cup ≤ 12 mm, and no met pad.
- **No scan (APPROX)**: arch ≤ 2 mm, posting ≤ 3°, and the angle is estimated. A rescan is recommended.
- **Flip-flops / slides**: there is no shoe counter, so heel cups are shallow (≤ 10 mm) and posting is gentle (≤ 4°).

### What the engine cannot judge
- Rigid vs flexible flat foot (needs a heel-raise / Jack's test), forefoot varus/valgus, ankle dorsiflexion, gait, pain. Staff must check these and override.
- The rearfoot angle is a geometric heuristic from a static, non-weight-bearing or partial-weight-bearing scan. It is not a goniometer measurement.
- The thresholds were tuned on the Fixifoot sample scans, not on a clinical dataset.

## References
- Chippaux JF. Contribution à l'étude de l'empreinte plantaire. 1985. Forriol F, Pascual J. Footprint analysis between three and seventeen years of age. *Foot Ankle* 1990;11:101-4.
- Williams DS, McClay IS. Measurements used to characterize the foot and the medial longitudinal arch: reliability and validity. *Phys Ther* 2000;80:864-71.
- Root ML, Orien WP, Weed JH. *Normal and Abnormal Function of the Foot.* 1977.
- Sobel E, Levitz S, et al. Natural history of the rearfoot angle: preliminary values in 150 children. *Foot Ankle Int* 1999;20:119-25.
- Kirby KA. *Foot and Lower Extremity Biomechanics.* Precision Intricast, 1997/2000/2002.
- Landorf KB, Keenan AM. Efficacy of foot orthoses. What does the literature tell us? *J Am Podiatr Med Assoc* 2000;90:149-58.
- Hsi WL, Kang JH, Lee XX. Optimum position of metatarsal pad in metatarsalgia for pressure relief. *Am J Phys Med Rehabil* 2005;84:514-20.
- Hayda R, Tremaine MD, Tremaine K, Banco S, Teed K. Effect of metatarsal pads and their positioning: a quantitative assessment. *Foot Ankle Int* 1994;15:561-6.
- Kang JH, Chen MD, Chen SC, Hsi WL. Correlations between subjective treatment responses and plantar pressure parameters of metatarsal pad treatment in metatarsalgia patients. *BMC Musculoskelet Disord* 2006;7:95.
- Burns J, Crosbie J, Ouvrier R, Hunt A. Effective orthotic therapy for the painful cavus foot. *J Am Podiatr Med Assoc* 2006;96:205-11.
- Bus SA, et al. IWGDF guidelines on offloading foot ulcers / footwear in persons with diabetes, 2023 update. *Diabetes Metab Res Rev* 2024.
- Evans AM. The flat-footed child – to treat or not to treat. *J Am Podiatr Med Assoc* 2008;98:386-93. Evans AM, Rome K. A Cochrane review of the evidence for non-surgical interventions for flexible pediatric flat feet. *Eur J Phys Rehabil Med* 2011;47:69-89.
- Gurney B. Leg length discrepancy. *Gait Posture* 2002;15:195-206.
- Welsh BJ, et al. A case-series study to explore the efficacy of foot orthoses in treating first metatarsophalangeal joint pain. *J Foot Ankle Res* 2010;3:17.

*Reviewed by (orthotist / podiatrist): ____________________  Date: ________*

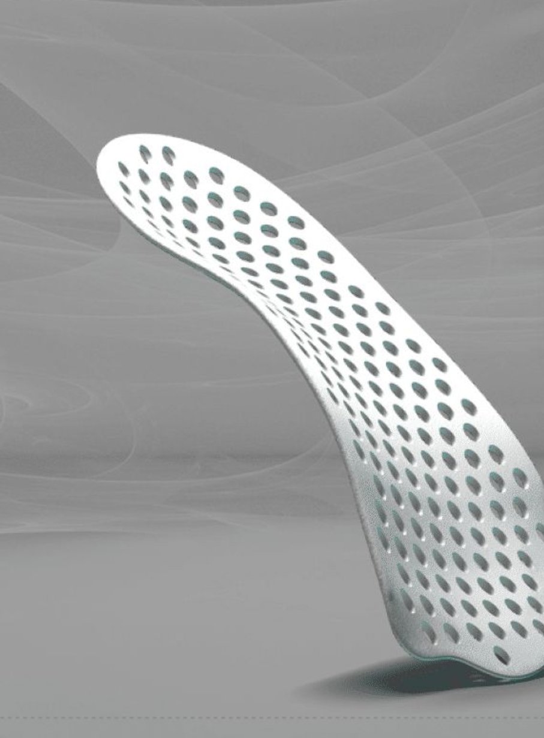
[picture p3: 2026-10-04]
assets/insole-perforated.jpg

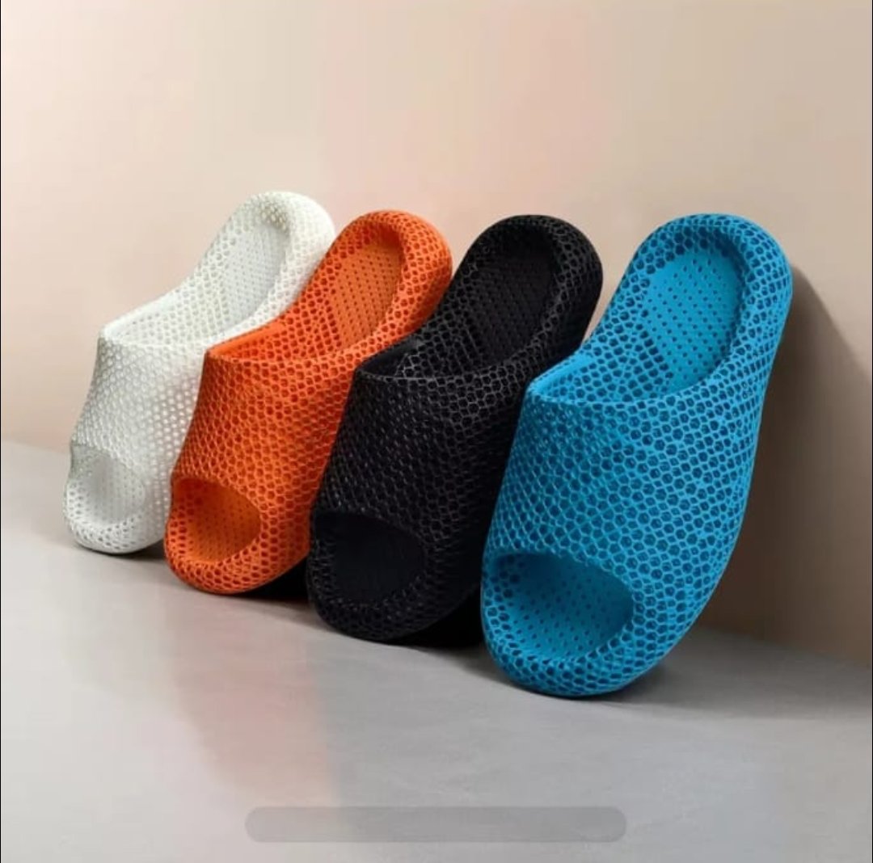
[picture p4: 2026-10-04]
assets/slide-lattice.jpg

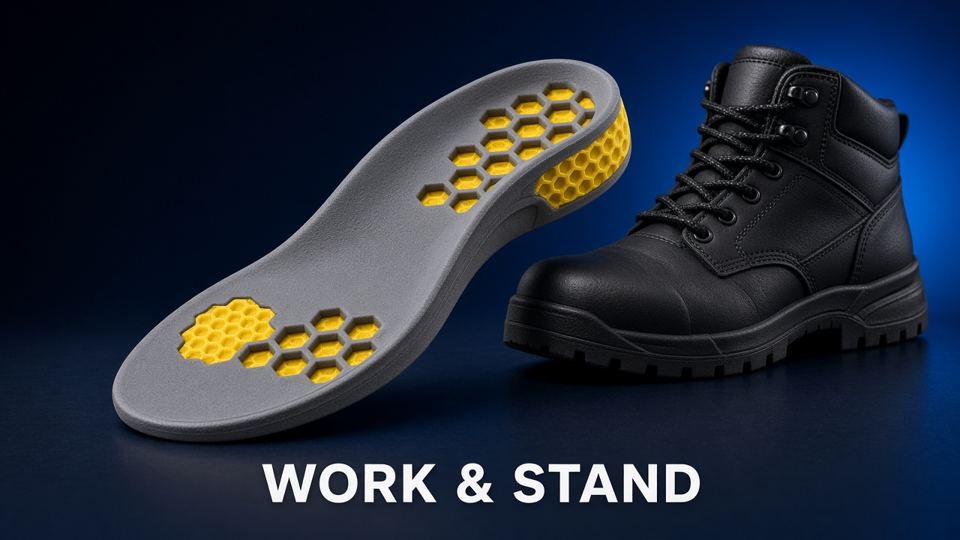
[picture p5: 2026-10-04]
catalog/work-hero.jpg

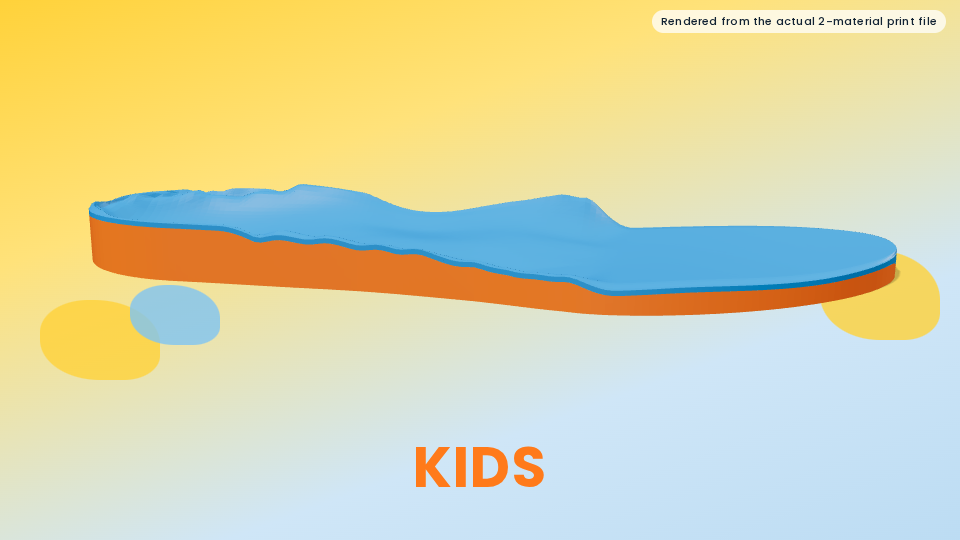
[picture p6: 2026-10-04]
catalog/kids-actual.png

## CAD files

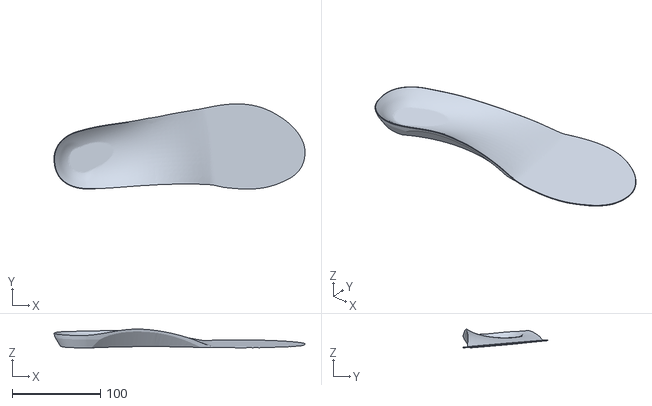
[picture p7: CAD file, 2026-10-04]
assets/templates/fixifoot-L90-full-length-R.stl
284.3 x 96.5 x 21.3

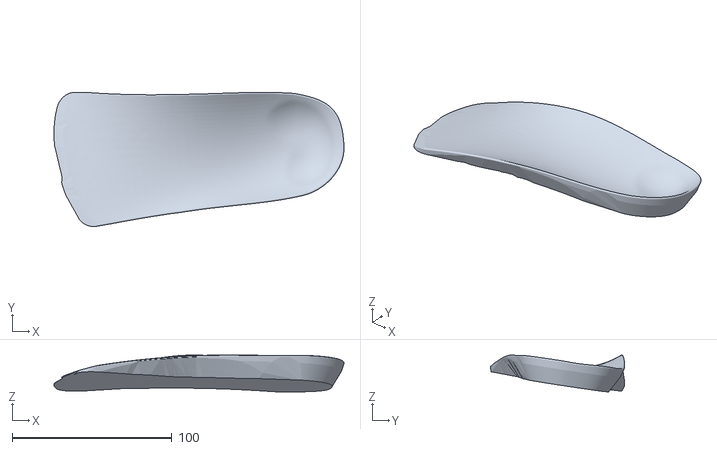
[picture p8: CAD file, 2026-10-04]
assets/templates/fixifoot-S90-three-quarter-R.stl
181.6 x 84.1 x 23.1

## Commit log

2026-10-04 Fixifoot demo v3
    [fixifoot-L90-full-length-R.stl, fixifoot-S90-three-quarter-R.stl]
2026-10-04 v6: real ventilation holes (perforated insole) and lattice openings (slide) in preview + STL, watertight
2026-10-04 v7.1: marketing illustrations as model cards, actual print preview in staff mode, catalog sheet v2
2026-10-04 v8: 2-material print files (multi-part 3MF, STL per body), 2-colour staff preview, actual renders
2026-10-04 v8.1: flip-flop/slide illustrations in picker, collection catalog, generic Everyday/Kids min 2.4 mm
2026-10-04 v9: design-first flow – catalog, designer (2-extruder colours, engraved initials), prices, design saved with order
2026-10-04 v10: production mode (real scan upload, staff manual measurements, offline PIN only when cloud unreachable) + in-browser PDF receipt with payment fields
2026-10-04 v11: CRM upgrade – customer card, tags, notes, scan history, order status pipeline (board + list), reminders, reports, CSV/Excel export, one-tap reorder
2026-10-04 v11.1: Continue without scan (shoe size / foot length + width + arch), scan-pending badge/filter/reminder, Add scan later regenerates print files, approximate-fit warning
2026-10-10 v13: Fixifoot Contour Two-Strap + Comfort Clog (scan-fitted footwear, 2-material 3MF, bed fit)
2026-10-10 v13.1: photo-style heroes for Contour Two-Strap + Comfort Clog, catalog rebuild
2026-10-10 v13.2: classic-look Two-Strap (rim, toe ridge, tread, molded buckles) + Comfort Clog (round top/side vents, rounded nose, swing strap on rivets), new heroes
